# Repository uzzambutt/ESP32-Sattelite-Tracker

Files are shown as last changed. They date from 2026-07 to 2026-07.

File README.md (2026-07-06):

<div align="center">

# ESP32 Satellite Tracker — Orbital Ops v10.0







**Designer:** [Muhammad Uzzam Butt](https://github.com/uzzambutt) // Made for Offtrack YSWS

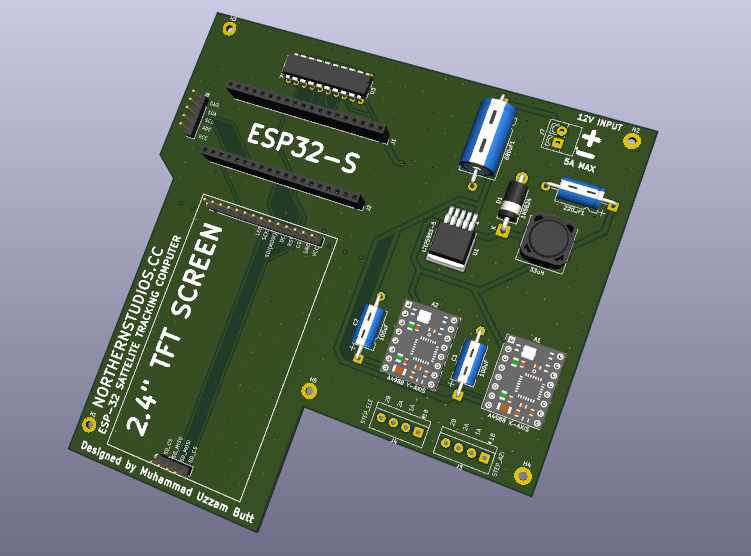
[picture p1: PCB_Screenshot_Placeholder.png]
PCB Screenshot Placeholder

*PCB screenshot, Uses SGP4 to calculate orbital sattelite mechanics natively.*

</div>

An ESP32-based automated satellite tracking system that drives a two-axis antenna mount using stepper motors, propagates satellite positions in real time with the SGP4 algorithm, and serves a live web dashboard over WiFi. The system supports a satellite queue, 24-hour pass scheduling, Doppler shift calculation, IMU-assisted elevation correction, weather data, satellite footprint visualization, and full EasyComm II compatibility for use with applications such as Look4Sat.

---

## Table of Contents

1. [Features](#features)
2. [Hardware Requirements](#hardware-requirements)
3. [Wiring Reference](#wiring-reference)
4. [Software Dependencies](#software-dependencies)
5. [File Structure](#file-structure)
6. [Configuration](#configuration)
7. [secrets.h Setup](#secretsh-setup)
8. [Building and Flashing](#building-and-flashing)
9. [First Boot](#first-boot)
10. [Web Dashboard](#web-dashboard)
11. [TFT Screen Reference](#tft-screen-reference)
12. [REST API Reference](#rest-api-reference)
13. [EasyComm II Interface](#easycomm-ii-interface)
14. [Satellite Queue](#satellite-queue)
15. [Pass Schedule](#pass-schedule)
16. [Weather Integration](#weather-integration)
17. [Auto-Park](#auto-park)
18. [OTA Updates](#ota-updates)
19. [Troubleshooting](#troubleshooting)

---

## Features

**Tracking and Propagation**
- Real-time SGP4/SDP4 satellite position propagation via the Sgp4 Arduino library
- Two-axis antenna control (azimuth and elevation) using AccelStepper with smooth acceleration
- Satellite queue: track up to 8 satellites sequentially, with automatic advancement after each pass
- 24-hour pass schedule computed for all queued satellites simultaneously, sorted by AOS time
- Real-time Doppler frequency shift calculation for multi-band (145.8, 435.8, 1268.0 MHz)
- Accurate satellite footprint computation using true orbital altitude and Earth-radius geometry
- Atmospheric drag refraction correction (Bennett 1982) for low-elevation passes

**Displays**
- 240x320 ST7789 TFT with 6 cycling screens:
  - Main HUD: target/current Az/El, pass countdown, Doppler, range, signal bars, radar
  - Pass Schedule: next 24 h passes for all queued satellites
  - IMU Drift Graph: real-time Kalman error history plot
  - Satellite Footprint: geometrically accurate overhead map with nadir, coverage area, arc angle
  - Orbital Elements: Inclination, RAAN, Eccentricity, Period, Perigee/Apogee, Orbit Type, TLE Age
  - Weather: temperature, feels-like, wind speed/direction, humidity, pressure, NOAA Kp Index
- Animated radar with satellite trajectory, AOS/LOS markers, and physics-based footprint ring
- Linux-style boot log with colour-coded status tags on TFT

**Networking and Control**
- WiFi station mode with AP fallback portal for credential setup
- Web dashboard served from PROGMEM over port 80 (ESPAsyncWebServer)
- WebSocket push telemetry at 1 Hz
- EasyComm II protocol over TCP port 4533 for Look4Sat and compatible clients
- mDNS hostname: sattracker.local
- ArduinoOTA firmware updates over WiFi

**Sensors and Intelligence**
- MPU6050 IMU with two-axis Kalman filter
- Accelerometer spike rejection, gyro deadband, and software low-pass filter
- **Note:** The MPU6050 is a 6-axis IMU (Gyro+Accel) and only measures gravity vectors. It can correct wind-drift or step-skipping on the **Elevation** axis, but it cannot determine absolute Azimuth heading without a magnetometer.
- NTP time synchronisation via pool.ntp.org
- Real-time NOAA Space Weather (Geomagnetic Kp index) parsing

**Persistence**
- TLE stored to LittleFS (/tle.txt) and re-loaded on boot
- Observer grid square, operating mode, weather city, and WiFi credentials stored in NVS (Preferences)

---

## Hardware Requirements

| Component | Notes |
|---|---|
| ESP32 development board | 30-pin or 38-pin, dual-core. Tested on ESP32-WROOM-32 |
| ST7789 TFT display | 240x320, SPI interface, 3.3 V logic |
| MPU6050 / GY-521 | I2C IMU, address 0x68 |
| Azimuth stepper driver | Step/Dir interface (e.g. DRV8825, A4988, TB6600) |
| Elevation stepper driver | Step/Dir interface |
| Azimuth stepper motor | NEMA 17 or NEMA 23 depending on load |
| Elevation stepper motor | NEMA 17 or NEMA 23 depending on load |
| Power supply | 12 V or 24 V for stepper drivers; 3.3 V/5 V for ESP32 |

---

## Wiring Reference

### TFT Display (ST7789, SPI)

| TFT Pin | ESP32 Pin | Config Constant |
|---|---|---|
| CS | GPIO 15 | TFT_CS |
| DC | GPIO 2 | TFT_DC |
| RST | GPIO 4 | TFT_RST |
| SCK | GPIO 18 | Hardware SPI (VSPI) |
| MOSI | GPIO 23 | Hardware SPI (VSPI) |
| VCC | 3.3 V | |
| GND | GND | |

### MPU6050 IMU (I2C)

| MPU6050 Pin | ESP32 Pin | Config Constant |
|---|---|---|
| VCC | 3.3 V | |
| GND | GND | |
| SDA | GPIO 21 | MPU_SDA |
| SCL | GPIO 22 | MPU_SCL |
| AD0 | GND | Sets I2C address to 0x68 |

### Azimuth Stepper Driver

| Signal | ESP32 Pin | Config Constant |
|---|---|---|
| STEP | GPIO 32 | AZ_STEP |
| DIR | GPIO 14 | AZ_DIR |
| ENABLE | GPIO 25 | ENABLE_PIN (shared with elevation) |

### Elevation Stepper Driver

| Signal | ESP32 Pin | Config Constant |
|---|---|---|
| STEP | GPIO 27 | EL_STEP |
| DIR | GPIO 26 | EL_DIR |
| ENABLE | GPIO 25 | ENABLE_PIN (shared with azimuth) |

### Button

| Function | ESP32 Pin | Notes |
|---|---|---|
| Screen cycle | GPIO 0 | IO0 / BOOT button. Active LOW, internal pull-up enabled |

---

## Software Dependencies

Install all of the following through the Arduino IDE Library Manager or manually:

| Library | Purpose |
|---|---|
| Sgp4 | SGP4/SDP4 orbital propagation |
| Adafruit_GFX | TFT graphics primitives |
| Adafruit_ST7789 | ST7789 TFT driver |
| AccelStepper | Stepper motor control with acceleration profiles |
| ESPAsyncWebServer | Asynchronous HTTP and WebSocket server |
| AsyncTCP | Required by ESPAsyncWebServer |
| ArduinoJson | JSON serialisation and deserialisation |
| NTPClient | NTP time synchronisation |
| ArduinoOTA | Over-the-air firmware updates |
| ESPmDNS | mDNS hostname resolution |
| LittleFS (built-in) | Filesystem for TLE storage |
| Preferences (built-in) | NVS key-value persistent storage |
| HTTPClient (built-in) | OpenWeatherMap API requests |
| Wire (built-in) | I2C communication for MPU6050 |

Board package: Install "ESP32 by Espressif Systems" via Boards Manager.
Tested with Arduino IDE 2.x and ESP32 core 2.0.x or 3.x.

---

## File Structure

```
ESP32_Sat_Tracker/
├── ESP32_Sat_Tracker.ino   Main sketch: globals, setup(), loop(), Core0 task,
│                            web server handlers, SGP4 runner, pass prediction,
│                            queue logic, Doppler, footprint, weather fetch
├── Config.h                 Pin definitions, colour palette, tuning parameters
├── secrets.h                WiFi credentials and OWM API key (excluded from VCS)
├── Display_Module.h         All TFT drawing functions (5 screens + radar engine)
├── Runtime_Module.h         EasyComm II parser and SGP4 runtime update function
├── Web_Pages.h              PROGMEM HTML/CSS/JS dashboard and WiFi setup portal
├── qrcodegen.h              QR code generator (used on boot screen)
└── data/                    LittleFS data directory
```

---

## Configuration

All hardware pins, timing constants, and tuning parameters are defined in Config.h. No other file needs editing for a pin reassignment.

### Key Constants

| Constant | Default | Description |
|---|---|---|
| BTN_PIN | 0 | GPIO for screen-cycle button |
| SCREEN_COUNT | 5 | Number of TFT screens |
| MAX_QUEUED_SATS | 8 | Maximum satellites in the tracking queue |
| MAX_SCHEDULED_PASSES | 48 | Maximum passes in the 24-hour schedule |
| PARK_IDLE_SEC | 300 | Seconds of inactivity before auto-park |
| PARK_AZ | 0.0 | Park azimuth in degrees |
| PARK_EL | 0.0 | Park elevation in degrees |
| WEATHER_INTERVAL_MS | 600000 | Weather fetch interval in milliseconds (10 min) |
| IMU_CORRECT_ENABLED | false | Enable IMU-assisted elevation correction |
| IMU_CORRECT_THRESH | 2.5 | Error threshold in degrees to trigger IMU correction |

### Steps Per Degree

The stepper resolution is set in the main sketch:

```cpp
const float STEPS_PER_DEG = 8.88f;
```

Calculate your value as:

    STEPS_PER_DEG = (motor_full_steps * driver_microsteps * gear_ratio) / 360

Example: 200 steps/rev * 16 microsteps * 1:1 gearbox / 360 = 8.89 steps/degree.

---

## secrets.h Setup

Create this file in the sketch directory. It is excluded from version control.

```cpp
// secrets.h
#pragma once

static const char* ssid     = "YOUR_WIFI_SSID";
static const char* password = "YOUR_WIFI_PASSWORD";

#define OWM_API_KEY "YOUR_OPENWEATHERMAP_API_KEY"
```

Obtain a free API key at https://openweathermap.org/api. The free tier is sufficient; the tracker uses only the Current Weather Data endpoint.

If OWM_API_KEY is not defined, weather fetching is disabled at compile time.

---

## Building and Flashing

1. Open ESP32_Sat_Tracker.ino in Arduino IDE 2.x.
2. Select your ESP32 board under Tools > Board > ESP32 Arduino.
3. Set the partition scheme to "Minimal SPIFFS (1.9MB APP with OTA)" or "Default 4MB with SPIFFS" under Tools > Partition Scheme.
4. Confirm secrets.h exists in the sketch directory.
5. Click Upload.

The first upload must be over USB. Subsequent uploads can use ArduinoOTA.

---

## First Boot

The TFT shows a Linux-style boot log:

```
[  OK  ]  IMU Kalman p=0.00
[  OK  ]  LittleFS mounted
[  OK  ]  Prefs: grid MM71dl
[ WARN ]  No saved TLE
[  ..  ]  Coupling WiFi radio
[  OK  ]  WiFi link up
[  OK  ]  IP 192.168.x.x
[  OK  ]  mDNS sattracker.local
[  OK  ]  NTP sync OK
[  OK  ]  WX Lahore
[  OK  ]  Starting Ops HUD
```

If WiFi fails after 15 seconds, the tracker creates a hotspot named AEROSPACE-TRACKER with password "groundstation". Browse to 192.168.4.1, enter your WiFi credentials, and the device reboots.

---

## Web Dashboard

Browse to http://sattracker.local or the IP address shown on the TFT.

The dashboard polls /api/status every 500 ms and maintains a live WebSocket connection for push updates. The dashboard is served by the ESP32 over port 80 and provides a complete SpaceX/Tesla style UI with animations and glassmorphism. It includes:

1. **Top Bar**: Weather, NOAA Kp index, UTC clock, status badges, and Night Mode toggle.
2. **Telemetry Stat-Strip**: Real-time Azimuth, Elevation, Range, and Doppler shift.
3. **Tactical Radar**: An animated sweeping radar with ghost trails, target lock beam, footprint ring, and crosshairs. Includes manual joystick controls.
4. **World Map Ground Track**: Real-time display of the satellite over an equirectangular world map with its physics-based visibility footprint.
5. **Orbital Database**: Upload raw 3-line TLEs or pull from Celestrak, view the active queue with live visibility dots, and parse raw orbital elements.
6. **24-Hour Pass Schedule**: Displays upcoming passes with maximum elevations and pass quality grades (A/B/C/F). Can be exported to CSV.
7. **QSO Log**: Store manual QSO/contact logs in your browser's local storage with timestamps.

---

## TFT Screen Reference

Press the IO0 button to cycle through screens.

| Screen | Name | Content |
|---|---|---|
| 0 | Main HUD | Target and current Az/El, AOS/LOS/countdown, range, Doppler, status indicators, animated radar with trajectory |
| 1 | Pass Schedule | Next passes for all queued satellites, upcoming passes in green, past in grey |
| 2 | IMU Drift Graph | Real-time plot of IMU pitch error vs. time, with correction threshold markers |
| 3 | Satellite Footprint | Overhead ground map: observer at centre, nadir crosshair, footprint ring centred on nadir point. Shows altitude, slant range, footprint radius, arc angle, coverage area in km2, and percentage of Earth surface covered |
| 4 | Weather | City, condition, temperature with feels-like, wind speed and compass direction, humidity, pressure, wind bar, last fetch time |

---

## REST API Reference

All endpoints are on port 80. Bodies are JSON.

### GET /api/status
Full telemetry payload. Called every 500 ms by the dashboard. Also pushed via WebSocket at /ws at 1 Hz.

### POST /api/tle
Upload a new primary TLE. Inserts at queue position 0 and begins tracking immediately.

    { "name": "ISS (ZARYA)", "line1": "1 25544U ...", "line2": "2 25544 ..." }

### POST /api/queue
Append a satellite to the queue without changing the active satellite.

    { "name": "NOAA 18", "line1": "1 28654U ...", "line2": "2 28654 ..." }

Returns {"status":"ok"} or {"status":"full"}.

### POST /api/queue/remove
Remove a satellite by zero-based index.

    { "idx": 2 }

### POST /api/queue/clear
Remove all satellites from the queue.

### GET /api/schedule
Returns the computed 24-hour pass schedule as a JSON array.

    [ { "sat": "ISS (ZARYA)", "aos": 1750000000, "los": 1750000400, "maxEl": 72.3, "aosAz": 315.1 }, ... ]

### POST /api/schedule/refresh
Triggers an immediate recompute. Call before polling /api/schedule.

### GET /api/path
Predicted trajectory of the current satellite for the radar.

    [ { "az": 315.2, "el": 0.0 }, { "az": 316.8, "el": 4.3 }, ... ]

### GET /api/passlog
Last 10 completed passes.

    [ { "sat": "AO-91", "time": "20:14:30", "maxEl": 34.7 }, ... ]

### POST /api/config
Update observer grid square and/or operating mode.

    { "grid": "MM71dl", "obMode": true }

obMode true = internal SGP4. obMode false = external EasyComm mode.

### POST /api/weather/city
Override weather query location by city name. Persists across reboots. Send an empty string to revert to coordinates.

    { "city": "Lahore" }

### POST /api/manual
Manually command Az/El. Only accepted in external mode.

    { "az": 180.0, "el": 45.0 }

### POST /api/wifi
Submit new WiFi credentials (AP portal only). Triggers reboot.

    { "ssid": "MyNetwork", "pass": "password" }

---

## EasyComm II Interface

The tracker listens on TCP port 4533. Compatible with Look4Sat, GPredict, and Ham Radio Deluxe rotator control.

| Command | Action |
|---|---|
| AZ\<value\> EL\<value\> | Set target azimuth and elevation in degrees |
| P \<az\> \<el\> | Positional command (alternate format) |
| P or p | Query current position; responds with AZ\<az\> EL\<el\> |

Movement commands are ignored in internal SGP4 mode.

---

## Satellite Queue

The queue holds up to 8 satellites (MAX_QUEUED_SATS). Position 0 is always the actively tracked satellite.

Adding: Upload via /api/tle to insert at position 0, or /api/queue to append.

Automatic advancement: When a pass ends and the satellite drops below the horizon, the tracker removes it from position 0 and begins tracking the next satellite in the queue.

Persistence: Position 0 is written to LittleFS on every TLE upload and reloaded on boot.

---

## Pass Schedule

The schedule scans the next 24 hours for every queued satellite, finds all visible passes, and stores up to 48 results sorted by AOS time. Computation runs in a dedicated FreeRTOS task on Core 0 to keep the display responsive.

Recompute is triggered automatically on boot, every 30 minutes, when the queue changes, and on demand via POST /api/schedule/refresh.

---

## Weather Integration

Weather data is fetched from OpenWeatherMap every 10 minutes (WEATHER_INTERVAL_MS).

Default mode: coordinates derived from the observer Maidenhead grid square.
City override: POST a city name to /api/weather/city. Stored in NVS. If OpenWeatherMap returns 404 for the city name, the firmware automatically clears the override and reverts to lat/lon.

---

## Auto-Park

In internal SGP4 mode, the antenna moves to PARK_AZ / PARK_EL after PARK_IDLE_SEC seconds of no activity and no active pass window. Any antenna movement resets the idle timer. Auto-park is disabled in external EasyComm mode.

---

## OTA Updates

After the initial USB flash, firmware can be updated wirelessly.

Arduino IDE: the device appears as "sattracker" under Tools > Port > Network Ports.

Command line:

    python espota.py -i sattracker.local -f ESP32_Sat_Tracker.ino.bin

No OTA password is set by default.

---

## Troubleshooting

**Display shows garbage or wrong colours**
Verify TFT_CS, TFT_DC, and TFT_RST in Config.h. Confirm the module is 3.3 V logic and VCC is correctly connected.

**IMU shows OFFLINE**
Check SDA/SCL wiring. The calibration requires the board to be stationary for about 1 second on boot.

**WiFi fails and goes to AP mode every boot**
Credentials are saved to NVS after a successful connection. If the router SSID or password has changed, connect to AEROSPACE-TRACKER and re-enter credentials.

**NTP never syncs**
The tracker uses pool.ntp.org over UDP port 123. Ensure the router does not block UDP port 123 outbound. The TFT HUD shows a red dot until sync succeeds; pass predictions and countdowns require sync.

**Stepper moves in the wrong direction**
Swap the DIR wiring on the affected driver, or swap one motor coil pair.

**Schedule shows passes for only one satellite**
Ensure all satellites are in the queue before clicking REFRESH SCHEDULE. If MAX_SCHEDULED_PASSES (48) is exhausted, increase the constant in Config.h and reflash.

**Weather shows the wrong city**
Send POST /api/weather/city with {"city":""} to clear the override and revert to observer coordinates.

**Screen freezes during schedule computation**
Fixed in v10.0: computeSchedule() now runs in a dedicated FreeRTOS task. If freezes persist, reduce MAX_QUEUED_SATS or MAX_SCHEDULED_PASSES in Config.h.

---

## License

This project is open source. See the repository for license details.

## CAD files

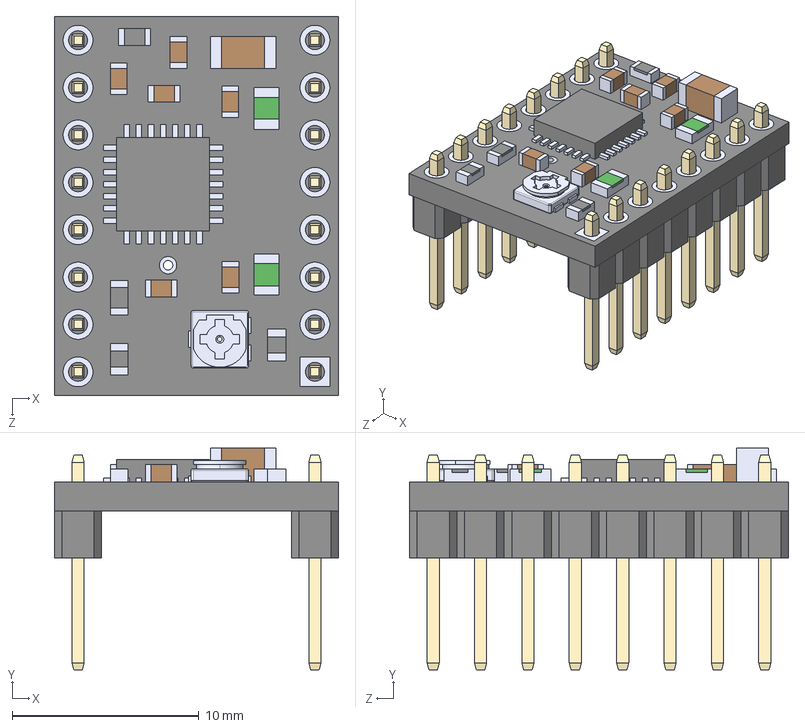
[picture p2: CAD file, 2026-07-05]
PCB/models/A4988 STEPPER MOTOR DRIVER CARRIER--3DModel-STEP-56544.STEP
15.2 x 11.9 x 20.3 mm

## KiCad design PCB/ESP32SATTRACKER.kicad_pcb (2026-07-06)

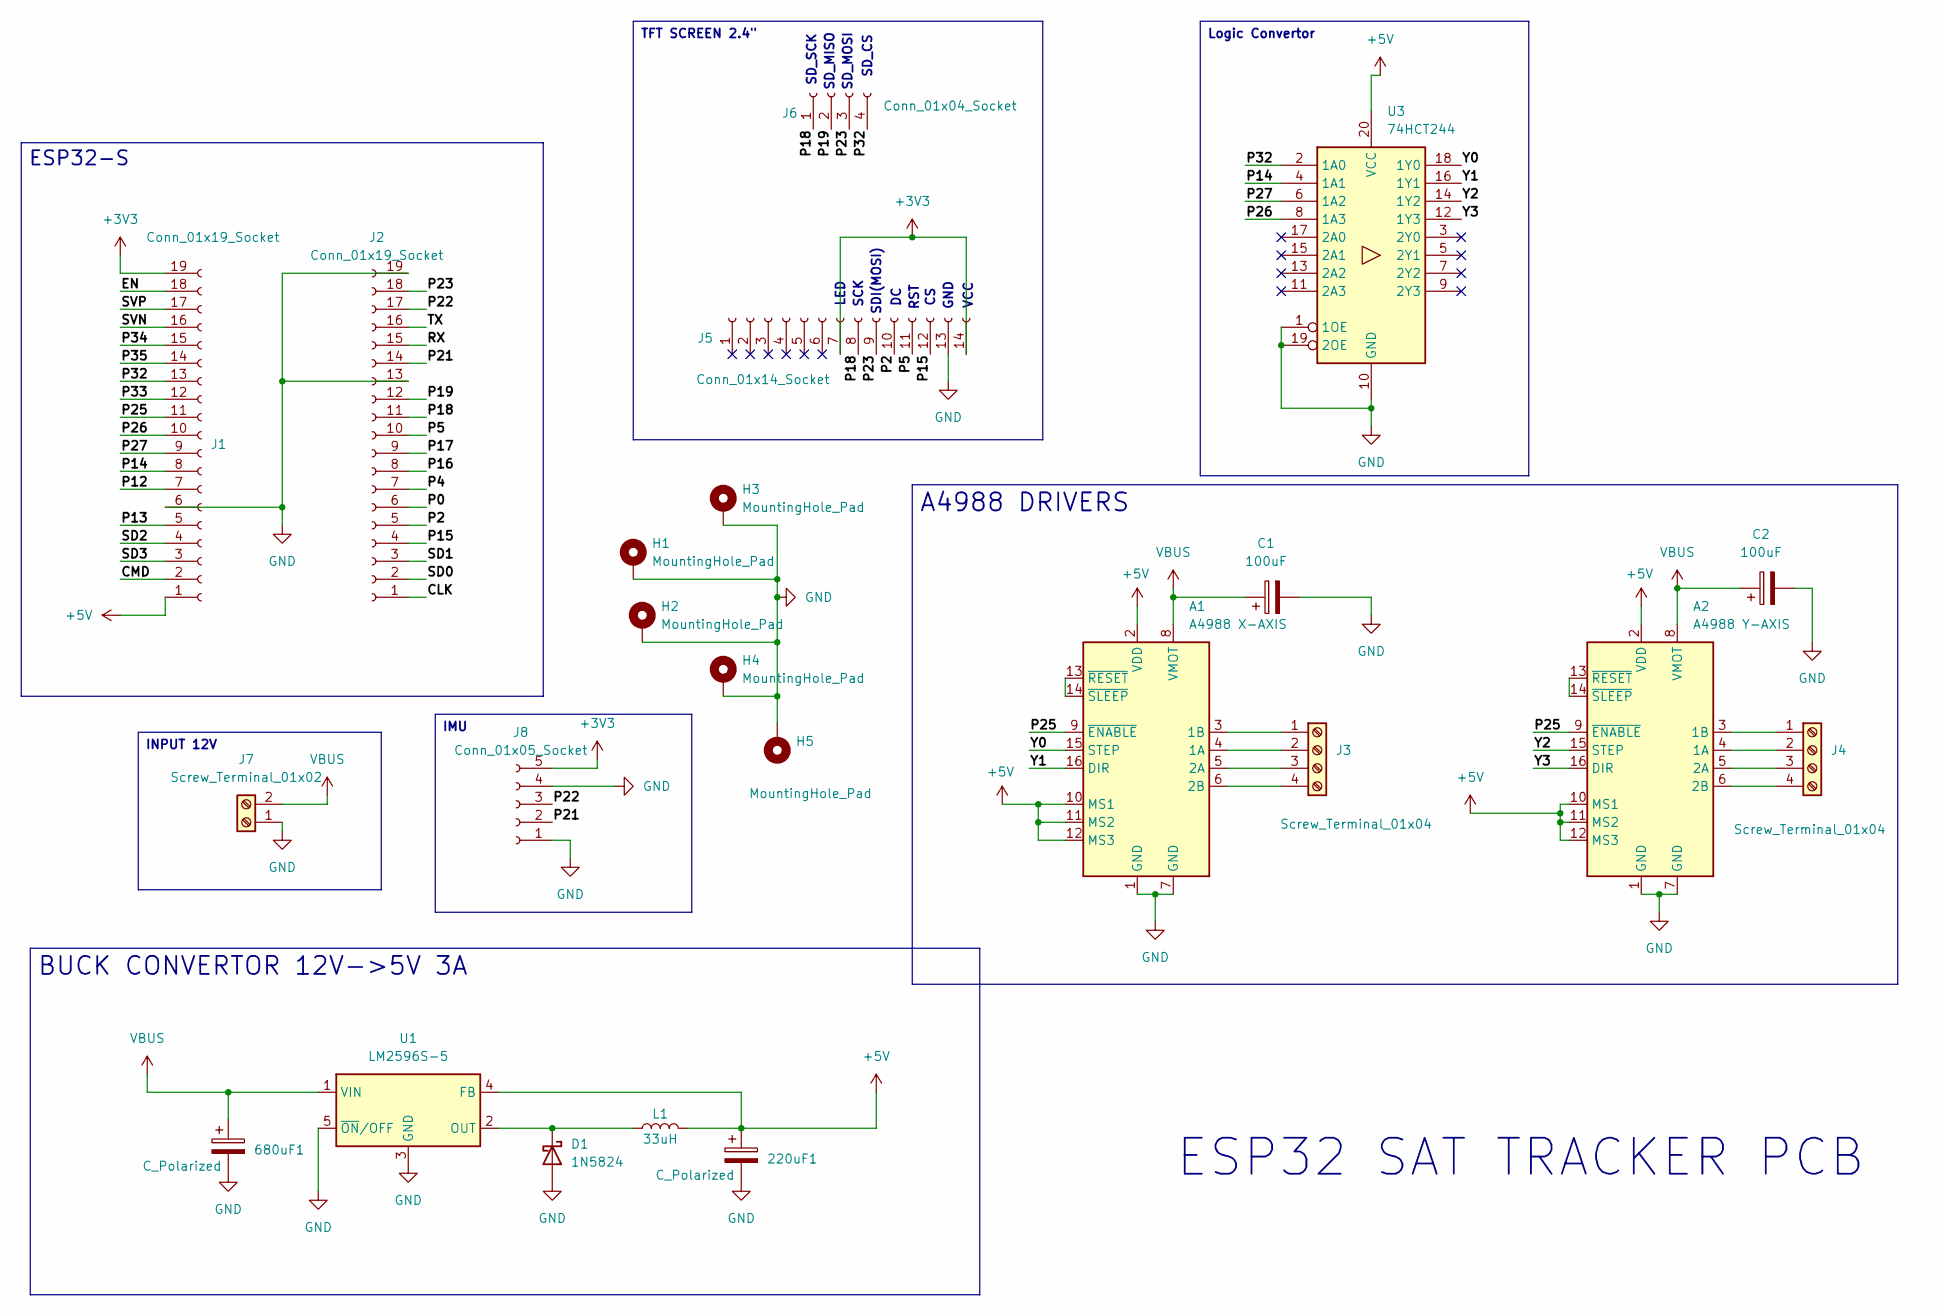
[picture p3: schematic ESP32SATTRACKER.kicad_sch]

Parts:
220uF1: C_Polarized; CP_Axial_L11.0mm_D6.0mm_P18.00mm_Horizontal
680uF1: C_Polarized; CP_Axial_L18.0mm_D10.0mm_P25.00mm_Horizontal
A1: A4988 X-AXIS; Pololu_Breakout-16_15.2x20.3mm
A2: A4988 Y-AXIS; Pololu_Breakout-16_15.2x20.3mm
C1, C2: 100uF; CP_Axial_L11.0mm_D6.0mm_P18.00mm_Horizontal
D1: 1N5824; D_DO-201AD_P15.24mm_Horizontal
H1, H2, H3, H4, H5: MountingHole_Pad; MountingHole_2.2mm_M2_Pad
J1, J2: Conn_01x19_Socket; PinSocket_1x19_P2.54mm_Vertical
J3, J4: Screw_Terminal_01x04; TerminalBlock_4Ucon_1x04_P3.50mm_Horizontal
J5: Conn_01x14_Socket; PinHeader_1x14_P2.54mm_Vertical
J6: Conn_01x04_Socket; PinHeader_1x04_P2.54mm_Vertical
J7: Screw_Terminal_01x02; TerminalBlock_4Ucon_1x02_P3.50mm_Vertical
J8: Conn_01x05_Socket; PinHeader_1x05_P2.54mm_Vertical
L1: 33uH; L_12x12mm_H8mm
U1: LM2596S-5; TO-263-5_TabPin3
U3: 74HCT244; DIP-20_W7.62mm

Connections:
+3V3: J1.19, J5.7, J5.14, J8.5
+5V: 220uF1.1, A1.2 (VDD), A1.10 (MS1), A1.11 (MS2), A1.12 (MS3), A2.2 (VDD), A2.10 (MS1), A2.11 (MS2), A2.12 (MS3), J1.1, L1.2, U1.4 (FB), U3.20 (VCC)
/CLK: J2.1
/CMD: J1.2
/EN: J1.18
/P0: J2.6
/P2: J2.5, J5.10
/P4: J2.7
/P5: J2.10, J5.11
/P12: J1.7
/P13: J1.5
/P14: J1.8, U3.4 (1A1)
/P15: J2.4, J5.12
/P16: J2.8
/P17: J2.9
/P18: J2.11, J5.8, J6.1
/P19: J2.12, J6.2
/P21: J2.14, J8.2
/P22: J2.17, J8.3
/P23: J2.18, J5.9, J6.3
/P25: A1.9 (~ENABLE), A2.9 (~ENABLE), J1.11
/P26: J1.10, U3.8 (1A3)
/P27: J1.9, U3.6 (1A2)
/P32: J1.13, J6.4, U3.2 (1A0)
/P33: J1.12
/P34: J1.15
/P35: J1.14
/RX: J2.15
/SD0: J2.2
/SD1: J2.3
/SD2: J1.4
/SD3: J1.3
/SVN: J1.16
/SVP: J1.17
/TX: J2.16
/Y0: A1.15 (STEP), U3.18 (1Y0)
/Y1: A1.16 (DIR), U3.16 (1Y1)
/Y2: A2.15 (STEP), U3.14 (1Y2)
/Y3: A2.16 (DIR), U3.12 (1Y3)
GND: 220uF1.2, 680uF1.2, A1.1 (GND), A1.7 (GND), A2.1 (GND), A2.7 (GND), C1.2, C2.2, D1.2 (A), H1.1, H2.1, H3.1, H4.1, H5.1, J1.6, J2.13, J2.19, J5.13, J7.1, J8.1, J8.4, U1.3 (GND), U1.5 (~ON/OFF), U3.1 (1OE), U3.10 (GND), U3.19 (2OE)
unnamed: A1.4 (1A), J3.2
unnamed: A1.3 (1B), J3.1
unnamed: A1.5 (2A), J3.3
unnamed: A1.6 (2B), J3.4
unnamed: A1.13 (~RESET), A1.14 (~SLEEP)
unnamed: A2.4 (1A), J4.2
unnamed: A2.3 (1B), J4.1
unnamed: A2.5 (2A), J4.3
unnamed: A2.6 (2B), J4.4
unnamed: A2.13 (~RESET), A2.14 (~SLEEP)
unnamed: D1.1 (K), L1.1, U1.2 (OUT)
VBUS: 680uF1.1, A1.8 (VMOT), A2.8 (VMOT), C1.1, C2.1, J7.2, U1.1 (VIN)

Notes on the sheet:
SCK
RST
SDI(MOSI)
SD_MISO
SD_MOSI
SD_CS
ESP32 SAT TRACKER PCB
LED
SD_SCK
VCC
GND
IMU
Logic Convertor
A4988 DRIVERS
TFT SCREEN 2.4"
BUCK CONVERTOR 12V->5V 3A
INPUT 12V
ESP32-S

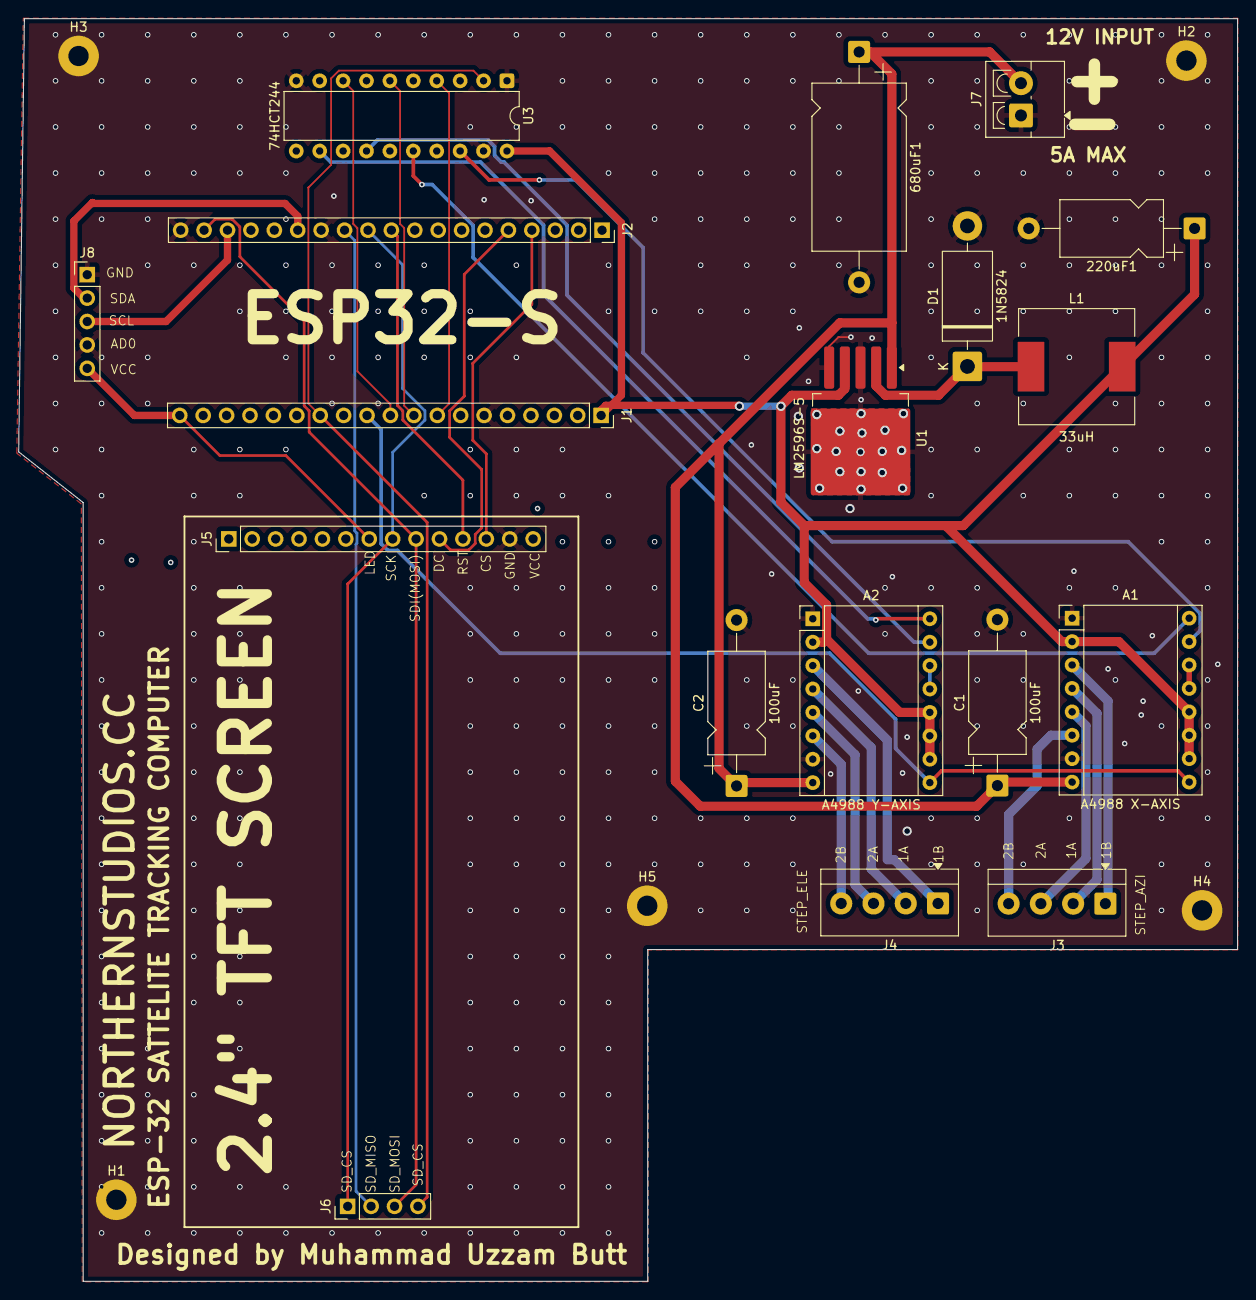
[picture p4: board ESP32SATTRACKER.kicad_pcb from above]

Board: 2 copper layers, 132.2 x 137.0 mm, 23 parts (0 on the bottom side), 32 nets.

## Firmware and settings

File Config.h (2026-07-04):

#ifndef CONFIG_H
#define CONFIG_H

#include <Arduino.h>

// ── IMU filter parameters ──────────────────────────────────────
#define MPU_ADDR       0x68
#define MPU_SDA        21
#define MPU_SCL        22
#define MPU_DLPF_CFG   4      // hardware 21 Hz LPF
#define ACCEL_LPF      0.15f  // software accel pre-smoother
#define GYRO_DEAD      0.8f   // deg/s deadband
#define SPIKE_LSB      800.0f // accel spike rejection threshold

// ── IMU correction ─────────────────────────────────────────────
#define IMU_CORRECT_ENABLED  false
#define IMU_CORRECT_THRESH   2.5f

// ── Button ─────────────────────────────────────────────────────
#define BTN_PIN     0       // IO0 — BOOT button on most ESP32 devboards
#define SCREEN_COUNT 8

// ── Power Monitor (INA226) ──────────────────────────────────────
#define INA226_ENABLED 0

// ── Satellite queue ────────────────────────────────────────────
#define MAX_QUEUED_SATS 8

// ── Azimuth cable wrap protection ──────────────────────────────
#define AZ_WRAP_LIMIT   450.0f  // max cumulative degrees before preferring opposite direction

// ── Backlash compensation (0 = disabled) ───────────────────────
#define AZ_BACKLASH_STEPS  0
#define EL_BACKLASH_STEPS  0

// ── Space weather fetch interval ───────────────────────────────
#define SPACE_WX_INTERVAL_MS  3600000UL  // Kp index every 1 hour

// ── Pass schedule ──────────────────────────────────────────────
#define MAX_SCHEDULED_PASSES 48

// ── Auto-park ──────────────────────────────────────────────────
#define PARK_IDLE_SEC   300   // park after 5 min idle with no pass
#define PARK_AZ         0.0f
#define PARK_EL         0.0f
#define PRE_POINT_SEC   120   // move to AOS start position 2 mins before pass

// ── Zenith Pass / Over-the-top flip ────────────────────────────
#define ALLOW_FLIP_OVER false // Set true if your mount can tilt 0 to 180 degrees backwards

// ── Weather ────────────────────────────────────────────────────
#define WEATHER_INTERVAL_MS  600000UL  // fetch every 10 min

// ── Radar safe zone ────────────────────────────────────────────
#define RADAR_SAFE_TOP   164
#define RADAR_SAFE_BOT   293
#define RADAR_SAFE_LEFT    0
#define RADAR_SAFE_RIGHT 239

// ================= PINS & COLORS =================
#define TFT_CS    15
#define TFT_DC     2
#define TFT_RST    4
#define SD_CS      33
#define AZ_STEP   32
#define AZ_DIR    14
#define EL_STEP   27
#define EL_DIR    26
#define ENABLE_PIN 25

// Palette: PURPLE primary (chrome/titles/frames), GREEN accent
// (values/OK/radar/sat dot), near-black background. (B)
// Safe RGB565 macro — no hand-computed bit math (avoids off-color bugs).
#define RGB565(r,g,b) ((uint16_t)((((uint16_t)(r)&0xF8)<<8)|(((uint16_t)(g)&0xFC)<<3)|(((uint16_t)(b))>>3)))

#define C_BLACK  0x0000
#define C_WHITE  0xFFFF
#define C_PRIMARY RGB565(190,160,225)   // light purple — titles, frames, target
#define C_ACCENT  RGB565(130,232,156)   // light green — values, OK, radar, sat dot
#define C_NEON    C_ACCENT              // alias kept: green = accent
#define C_GREEN   RGB565( 60,220,120)
#define C_LIME    RGB565(170,240,180)
#define C_AMBER   C_PRIMARY             // alias kept: amber→purple (TGT/EL/titles)
#define C_ORANGE  RGB565(255,178,140)   // soft warning (countdown)
#define C_RED     RGB565(255,112,130)
#define C_CYAN    C_PRIMARY             // footprint screen chrome → purple
#define C_MGRAY   RGB565(125,120,142)   // muted text (slightly purple-tinted)
#define C_DGRAY   RGB565( 56,50,78)     // frame/border (purple-tinted dark)
#define C_FAINT   RGB565( 36,30,56)
#define C_HDRBG   RGB565( 28,20,44)     // dark purple header bar
#define C_PNLG    RGB565( 24,44,30)     // dark green panel-title fill
#define C_PNLA    RGB565( 32,24,52)     // dark purple panel-title fill
#define C_RING    RGB565( 72,60,104)    // radar ring (purple-tint)
#define C_DRED    RGB565( 80,20,40)

#endif // CONFIG_H

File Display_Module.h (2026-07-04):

#ifndef DISPLAY_MODULE_H
#define DISPLAY_MODULE_H

// ================= BOOT SCREENS =================
void drawBootScreen(){
  tft.fillScreen(C_BLACK);
  // purple header bar, green accent line (B/C)
  tft.fillRect(0,0,240,28,C_HDRBG);tft.fillRect(0,28,240,2,C_ACCENT);
  tft.fillRect(0,0,4,28,C_ACCENT);tft.fillRect(236,0,4,28,C_PRIMARY);
  tft.setTextColor(C_ACCENT);tft.setTextSize(1);
  tft.setCursor(8,5);tft.print("ESP32 SATELLITE TRACKER");
  tft.setTextColor(C_PRIMARY);tft.setCursor(8,16);tft.print("v10.0  //  ORBITAL OPS");
  tft.setTextColor(C_MGRAY);tft.setCursor(8,38);tft.print("DEVELOPER:");
  tft.setTextColor(C_WHITE);tft.setCursor(8,50);tft.print("Muhammad Uzzam Butt");
  tft.drawFastHLine(4,64,232,C_DGRAY);
  tft.setTextColor(C_MGRAY);tft.setCursor(8,70);tft.print("SCAN FOR SOURCE CODE:");
  const char* url="https://github.com/uzzambutt/ESP32-Sattelite-Tracker";
  uint8_t *qr=(uint8_t*)malloc(qrcodegen_BUFFER_LEN_MAX);
  uint8_t *tmp=(uint8_t*)malloc(qrcodegen_BUFFER_LEN_MAX);
  if(qr&&tmp){
    if(qrcodegen_encodeText(url,tmp,qr,qrcodegen_Ecc_LOW,
       qrcodegen_VERSION_MIN,qrcodegen_VERSION_MAX,qrcodegen_Mask_AUTO,true)){
      int qs=qrcodegen_getSize(qr),ps=3;
      int ox=(240-qs*ps)/2,oy=84;
      tft.fillRect(ox-4,oy-4,qs*ps+8,qs*ps+8,C_WHITE);
      for(int y=0;y<qs;y++)
        for(int x=0;x<qs;x++)
          if(qrcodegen_getModule(qr,x,y))
            tft.fillRect(ox+x*ps,oy+y*ps,ps,ps,C_BLACK);
    }
  }
  if(qr)free(qr);if(tmp)free(tmp);
  // tty-style footer prompt
  tft.fillRect(0,300,240,20,C_HDRBG);tft.fillRect(0,298,240,2,C_ACCENT);
  tft.setTextColor(C_PRIMARY);tft.setCursor(8,307);tft.print("user@orbital");
  tft.setTextColor(C_MGRAY);tft.setCursor(96,307);tft.print(":~$ boot");
}

// â”€â”€ Linux-tty style boot log (C) â”€â”€â”€â”€â”€â”€â”€â”€â”€â”€â”€â”€â”€â”€â”€â”€â”€â”€â”€â”€â”€â”€â”€â”€â”€â”€â”€â”€â”€â”€â”€
// Each line prints a dmesg-ish status tag then the message, on a black
// terminal. Auto-scrolls when it hits the bottom. A blinking block
// cursor sits after the last line like a real VT.
//   status: 0=OK(green) 1=FAILED(red) 2=BUSY/..(purple) 3=WARN(orange) 4=info(white)
void printBootLine(String msg,int status){
  Serial.println("[BOOT] "+msg);
  const int lineH=11, topY=28, botY=300, headerH=22;
  if(terminalY+lineH>botY){
    // scroll: clear region and restart under a fresh tty header
    tft.fillScreen(C_BLACK);
    tft.fillRect(0,0,240,headerH,C_HDRBG);
    tft.fillRect(0,headerH,240,2,C_ACCENT);
    tft.setTextColor(C_ACCENT);tft.setTextSize(1);
    tft.setCursor(6,7);tft.print("orbital tty1");
    tft.setTextColor(C_MGRAY);tft.setCursor(170,7);tft.print("boot log");
    tft.drawFastHLine(0,headerH+2,240,C_DGRAY);
    terminalY=topY;
  }
  tft.setTextSize(1);
  // status tag in fixed-width bracket
  const char* tag; uint16_t tc;
  switch(status){
    case 0: tag="[  OK  ]"; tc=C_ACCENT; break;
    case 1: tag="[FAILED]"; tc=C_RED;    break;
    case 2: tag="[  ..  ]"; tc=C_PRIMARY;break;
    case 3: tag="[ WARN ]"; tc=C_ORANGE; break;
    default:tag="[ INFO ]"; tc=C_MGRAY;  break;
  }
  tft.setTextColor(tc);tft.setCursor(4,terminalY);tft.print(tag);
  // message â€” truncate to fit ~26 chars after the 52px tag
  tft.setTextColor(C_WHITE);tft.setCursor(54,terminalY);
  if(msg.length()>26)msg=msg.substring(0,26);
  tft.print(msg);
  terminalY+=lineH;
  // blinking block cursor on the next prompt line
  tft.setTextColor(C_ACCENT);tft.setCursor(4,terminalY);tft.print("_");
  delay(70);
  tft.fillRect(4,terminalY,6,8,C_BLACK);  // blink off
}

// legacy entry point â€” kept so existing call sites compile; maps to INFO
void printBootTerminal(String msg){ printBootLine(msg,4); }

void tftDrawAPMode(){
  tft.fillScreen(C_BLACK);
  tft.fillRect(0,0,240,24,C_DRED);tft.fillRect(0,0,4,24,C_RED);tft.fillRect(236,0,4,24,C_RED);
  tft.setTextColor(C_WHITE);tft.setTextSize(1);tft.setCursor(8,5);tft.print("! NETWORK LINK FAILED !");
  tft.setTextColor(C_AMBER);tft.setCursor(8,15);tft.print("ENTERING SETUP MODE");
  tft.drawFastHLine(0,24,240,C_RED);tft.setTextColor(C_RED);tft.setTextSize(2);
  tft.setCursor(10,32);tft.print("WIFI FAIL");
  tft.drawRoundRect(2,58,236,128,4,C_AMBER);tft.fillRect(3,59,234,12,C_PNLA);
  tft.setTextColor(C_AMBER);tft.setTextSize(1);tft.setCursor(6,61);tft.print("[ SETUP INSTRUCTIONS ]");
  tft.drawFastHLine(3,71,234,C_DGRAY);
  tft.setTextColor(C_AMBER);tft.setCursor(6,76);tft.print("1.");
  tft.setTextColor(C_MGRAY);tft.setCursor(20,76);tft.print("Join WiFi: AEROSPACE-TRACKER");
  tft.setTextColor(C_AMBER);tft.setCursor(6,92);tft.print("2.");
  tft.setTextColor(C_MGRAY);tft.setCursor(20,92);tft.print("Password: groundstation");
  tft.setTextColor(C_AMBER);tft.setCursor(6,108);tft.print("3.");
  tft.setTextColor(C_MGRAY);tft.setCursor(20,108);tft.print("Browse to: 192.168.4.1");
  tft.drawRoundRect(2,150,236,24,4,C_DGRAY);
  tft.setTextColor(C_AMBER);tft.setCursor(6,158);tft.print("WAITING FOR CREDENTIALS...");
  tft.fillRect(0,300,240,20,C_DRED);tft.setTextColor(C_WHITE);tft.setCursor(8,307);tft.print("AP MODE  |  192.168.4.1");
}

// ================= STATIC HUD FRAME =================
void tftDrawStaticFrame(){
  tft.fillScreen(C_BLACK);resetTftCache();
  tft.fillRect(0,0,240,16,C_HDRBG);tft.fillRect(0,16,240,2,C_NEON);tft.fillRect(0,0,3,16,C_AMBER);
  tft.setTextColor(C_NEON);tft.setTextSize(1);tft.setCursor(7,4);tft.print("ORBITAL OPS");
  tft.setTextColor(C_MGRAY);tft.setCursor(96,4);tft.print("UTC");
  tft.drawRect(2,20,236,54,C_NEON);tft.fillRect(3,21,234,11,C_PNLG);
  tft.setTextColor(C_NEON);tft.setCursor(6,23);tft.print("TGT");
  tft.drawFastHLine(3,32,234,C_FAINT);tft.drawFastVLine(118,33,40,C_FAINT);
  tft.setTextColor(C_MGRAY);tft.setCursor(6,40);tft.print("AZ");tft.setCursor(124,40);tft.print("EL");
  const char* cl[5]={"ENG","MOT","L4S","NTP","MEM"};
  for(int i=0;i<5;i++){int x=2+i*48;tft.drawRect(x,78,44,22,C_DGRAY);tft.fillRect(x+1,79,42,8,C_FAINT);tft.setTextColor(C_MGRAY);tft.setCursor(x+13,79);tft.print(cl[i]);}
  tft.drawRect(2,104,236,42,C_AMBER);tft.fillRect(3,105,234,11,C_PNLA);
  tft.setTextColor(C_AMBER);tft.setCursor(6,107);tft.print("PASS PREDICTION");
  tft.drawFastHLine(3,116,234,C_FAINT);tft.drawFastVLine(118,117,28,C_FAINT);
  tft.setTextColor(C_MGRAY);
  tft.setCursor(6,120);tft.print("AOS:");tft.setCursor(124,120);tft.print("MAX:");
  tft.setCursor(6,133);tft.print("LOS:");tft.setCursor(124,133);tft.print("T- :");
  tft.setCursor(6,151);tft.print("DST:");tft.setCursor(124,151);tft.print("DOP:");
  tft.fillRect(0,302,240,18,C_HDRBG);tft.fillRect(0,300,240,2,C_NEON);
  tft.setTextColor(C_NEON);tft.setCursor(6,307);
  tft.print(isAPMode?"192.168.4.1":WiFi.localIP().toString());
  tft.setTextColor(C_MGRAY);tft.setCursor(120,307);tft.print(maidenhead);
  newPathReady=true;
}
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

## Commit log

2026-06-19 v10.1: fix queue/schedule/footprint/weather bugs + purple/green restyle
    Firmware logic fixes (root causes):
    - A1: buildTelemetryJson StaticJsonDocument 768->1536; the full 8-sat
    queue + weather overflowed it, corrupting /api/status JSON and freezing
    the web UI so the queue list would not update or clear.
    - A2: /api/tle queue-insert memmove was unbounded; a full queue wrote
    satQueue[8] out of bounds. Now capped before insert.
    - A3: computeSchedule() only ran at boot + every 30 min, so sats queued
    after boot never appeared in the schedule. Added scheduleDirty flag set
    on every queue/TLE change and on web refresh; Core0 recomputes when
    dirty. Web REFRESH now POSTs /api/schedule/refr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
2026-06-23 split up files and fixed bugs
    [Config.h, Display_Module.h]
2026-06-24 Update README with new UI and IMU notes
2026-07-04 working on schematic, halfway done ~45 mins elapsed
    [ESP32SATTRACKER.kicad_pcb, ESP32SATTRACKER.kicad_sch]
2026-07-04 80% completed
    [ESP32SATTRACKER.kicad_sch]
2026-07-05 completed diagram
    [ESP32SATTRACKER.kicad_sch]
2026-07-05 assigned footprints
    [ESP32SATTRACKER.kicad_sch]
2026-07-05 completed the PCB
    [ESP32SATTRACKER.kicad_pcb, ESP32SATTRACKER.kicad_sch]
2026-07-05 Update README with open source badges and PCB placeholder
    [A4988 STEPPER MOTOR DRIVER CARRIER--3DModel-STEP-56544.STEP, ESP32SATTRACKER.kicad_pcb, ESP32SATTRACKER.kicad_sch]
2026-07-06 rerouted the ESP32, IMU AND TFT AGAIN CUZ I AGAIN MESSED UP THE ESP32 ARRANGEMENT AND INVERTED IT!!
    [ESP32SATTRACKER.kicad_pcb]
2026-07-06 Add GERBER files
    [ESP32SATTRACKER-B_Cu.gbr, ESP32SATTRACKER-B_Mask.gbr, ESP32SATTRACKER-B_Paste.gbr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]
2026-07-06 update gerber zip

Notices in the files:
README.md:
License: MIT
